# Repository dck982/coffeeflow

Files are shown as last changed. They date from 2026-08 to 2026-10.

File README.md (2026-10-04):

# coffeeflow

Modification d'une **Profitec Go** pour du *flow profiling* et du *brew by weight* : l'infusion se lance depuis un écran tactile, la pression se module, et elle s'arrête toute seule au poids cible.

## Machine d'origine

- Vanne solénoïde trois voies + pompe vibratoire 35 W + boiler
- Petit boîtier PID : consigne / mesure de température du boiler, chrono
- Vanne OPV pour limiter la pression
- Plomberie en **1/8"**
- Connexions électriques internes : cosses à languette **FASTON 6,3 × 0,8 mm** (pas de piggyback : la dérivation se fait dans un boîtier imprimé)
- Deux compartiments : **technique** (hydraulique, boiler, groupe, électricité) et **réservoir d'eau**
- Bouton **brew** en façade (Ø 16 mm) : démarrait vanne + pompe. **Supprimé** — le trou sert de passe-câble CAN vers l'écran
- LED de façade : ses cosses FASTON ont été réutilisées, la LED est réalimentée depuis le boîtier PS

## Ce que la modification ajoute

La modification pilote la pompe, la vanne et la résistance de chaudière :

1. **Pompe** — un dimmer AC 4 A en mode **DimmerLink** (I2C) fait varier la pression.
2. **Vanne solénoïde** — un SSR ouvre et ferme le circuit d'infusion.
3. **Chaudière** — le SSR Keysolu/Maxwell fourni avec la machine commande la résistance de chauffe ; sa commande 5 V passe par un HW-399 dans `boitier_pid`.

Plus de bouton brew, plus de relais NC de « mode manuel » : la commande passe par l'écran. Le système est alimenté dès que l'**interrupteur principal** de la machine est enfoncé.

Deux retours capteurs, sur le module interne :

- **Pression** sur la plomberie, en amont de la vanne (I2C 3,3 V)
- **Débit** en amont de la pompe, côté basse pression (le capteur ne tient que 3 bar)

La **température de la chaudière** vient de la sonde NTC vissée en G1/8 dans la chaudière. Son câble rejoint le boîtier de l'écran, proche de la sonde, où un ADS1115 la mesure via un pont alimenté par le **3V3 et le GND du port Sensor AD du Waveshare**. Voir [la calibration NTC/ADS1115](docs/ntc_ads1115_calibration.md).

Le **poids** vient d'une balance **Acaia Lunar** en **BLE**, lue par l'écran. La pesée du drip tray par cellule de charge est **abandonnée pour l'instant** (peser quelques grammes sur un plateau d'un kilo) — pièces et cotes conservées dans `print/parts/*_pesage*` et `docs/driptray.md`.

## Architecture électronique

**Cinq boîtiers imprimés, deux nœuds ESP32-S3.** Le 230 V ne sort pas de la machine.

```
             interrupteur principal (230 V L/N)
                          │
                    [boitier_ps]      intérieur, face ouest, le long du réservoir
                  alim RECOM 5 W · Wago            │
                          │                        └── L/N → LED de façade
              ┌───────────┴───────────┐
          5 V / GND                 L/N ×2
              │                       │
   ┌──────────┴──────────┐      [boitier_ac]   accolé à boitier_dc
   │                     │       dimmer · SSR
[boitier_dc]        [screen_*]        │    │
 XIAO ESP32-S3       Waveshare 4,3"   │    └── L/N → vanne solénoïde
 + Grove Shield      ESP32-S3         └────── L/N → pompe vibratoire
 + CAN Pal           UI · Wi-Fi · BLE
      │                   └── I2C ← ADS1115 ← NTC chaudière
      │                   │
      └──── bus CAN ──────┘   paire torsadée, par le trou Ø16 de l'ex-bouton brew
      │
      ├── I2C 3,3 V ─→ dimmer (DimmerLink)
      ├── GPIO ──────→ SSR vanne (M5Stack Unit SSR)
      ├── GPIO 3 ────→ [boitier_pid : HW-399] ─→ SSR chaudière ─→ résistance
      ├── I2C 3,3 V ←─ capteur de pression XDB401
      └── GPIO ──────← débitmètre Digmesa
```

| Nœud | Alias | Où | Rôle |
| --- | --- | --- | --- |
| **Waveshare 4,3" LCD Touch** (ESP32-S3-WROOM) | *screen*, *écran*, *waveshare* | façade, dans `screen_base` + `screen_wedge` | Interface utilisateur, algorithme d'infusion, **Wi-Fi et BLE** (Acaia Lunar) ; raccordement de la NTC chaudière via ADS1115 |
| **Seeed XIAO ESP32-S3** sur Grove Shield | *xiao*, *module interne*, *module capteurs*, *contrôleur* | intérieur, `boitier_dc`, zone froide entre le module PID et le cadran manomètre | Capteurs (XDB401, Digmesa) et actionneurs (dimmer pompe, SSR vanne, commande du SSR chaudière via HW-399) |

Les deux nœuds parlent **CAN**. L'écran est le seul à utiliser la radio.

Maquette Three.js de la machine (ouvrir dans le navigateur) : `docs/profitec_go.html`.

### Pourquoi un XIAO à l'intérieur

L'Atom Echo S3R de l'ancienne architecture est spécifié à **40 °C**. Le XIAO ESP32-S3 tient **85 °C**. Le compartiment technique monte à 45–50 °C : la marge de l'Atom est nulle, celle du XIAO est utilisable. L'écran Waveshare reste en façade, hors de cette enceinte.

---

## Boîtiers

| Boîtier | Pièces `print/parts/` | Où | Contenu |
| --- | --- | --- | --- |
| **PS** | `boitier_ps`, `couvercle_ps` | intérieur, contre la face **gauche** vue de face, le long de la séparation avec le réservoir | Alim RECOM, Wago 230 V (entrée + LED façade), Wago 5 V / GND |
| **DC** | `boitier_dc` | intérieur, **zone froide** entre le module PID et le cadran manomètre | XIAO + Grove Shield, Adafruit CAN Pal, Wago 5 V |
| **AC** | `boitier_ac` | accolé au DC | Dimmer 4 A DimmerLink, M5Stack Unit SSR |
| **PID** | `boitier_pid`, `couvercle_pid` | compartiment technique, près du contrôleur PID d'origine | HW-399, connecteurs XH et Wago de distribution 5 V / GND ; commande du SSR chaudière |
| **UI** | `screen_base`, `screen_wedge` | façade de la machine | Écran Waveshare 4,3", ADS1115 et raccordement NTC ; emplacement AMS1117 inutilisé |

Les boîtiers **AC et DC sont côte à côte et reliés par leur couvercle**, qui est commun aux deux (`couvercle_acdc`, assemblage `ensemble_boitiers`).

---

## Composants

| Rôle | Matériel retenu | Fiche |
| --- | --- | --- |
| UI / algo / radio | **Waveshare ESP32-S3-Touch-LCD-4.3** — 800 × 480, TJA1051T/3 CAN intégré, alim USB-C 5 V | `docs/datasheets/waveshare-4-3-lcd-touch.md` |
| MCU interne | **Seeed Studio XIAO ESP32-S3** sur **Grove Shield for XIAO** (8 ports Grove) | `docs/datasheets/xiao.pdf`, `docs/datasheets/grove-expansion-board.md` |
| Transceiver CAN côté XIAO | **Adafruit CAN Pal** (TJA1051T/3), [produit 5708](https://www.adafruit.com/product/5708) | — |
| Dimmer pompe | **RBDimmer AC Dimmer 4 A 1 canal**, logique 3,3 V, mode **[DimmerLink](https://www.rbdimmer.com/docs/dimmerlink-overview)** ([boutique](https://www.rbdimmer.com/shop/ac-dimmers-1/ac-dimmer-module-4a-1-channel-33v5v-logic-ac-400v-4a-6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)) | — |
| SSR vanne | **M5Stack Unit SSR** (2 A), commande 3,3–5 V, zero-crossing MOC3043M | `docs/datasheets/m5stack-unit-ssr.md` |
| SSR chaudière | **Keysolu/Maxwell KS53 D-24Z20N-LQ**, fourni avec la machine ; en série entre la phase de l'interrupteur principal et la résistance, suivie de la protection thermique puis du neutre ; commande DC +/− via HW-399, FASTON mâles 4,8 mm | [Câblage](docs/cablage.md#ssr-de-chaudière-fourni-avec-la-machine) |
| Interface SSR chaudière | **HW-399 4-channel Optocoupler**, voie IN4 / OUT4, logé dans `boitier_pid` | `docs/cablage.md` |
| Température chaudière | Sonde **NTC G1/8**, pont sur le port Sensor AD et breakout **ADS1115 16 bits** sur l'I2C de l'écran | [Calibration NTC/ADS1115](docs/ntc_ads1115_calibration.md) |
| Pression | **Yufavor XDB401**, I2C, filetage **G1/8** | `docs/datasheets/xidibei_xdb401.pdf` |
| Débit | **Digmesa FHKSC 932-9525-B**, buse **1,00 mm** | `docs/datasheets/flowmeter-digmesa.pdf`, `docs/debitmetres.md` |
| Alimentation | **RECOM RAC05-05SK/277/W** — 5 W, 5 V / 1 A, encapsulée, 85–305 VAC, version fils | `docs/datasheets/RAC05-K_277.pdf` |
| Poids | **Acaia Lunar**, BLE, lue par l'écran | — |
| Câble | **Helutherm 145** — 0,75 mm² pour les ajouts 230 V, 0,25 mm² en 5 V / signaux / CAN ; puissance chaudière en 1 mm² | `docs/datasheets/helutherm145.pdf` |

Actionneurs d'origine pilotés : vanne solénoïde **OLAB 08252L50-A14-1A-G** (bobine 08000BH-J5IV, 15 VA, 220/230 V 50/60 Hz, orifice Ø 1,4 mm, joint FKM, laiton CW510L, NSF) et pompe vibratoire **OLAB Silent Green 35 W**.

---

## Le module interne (XIAO)

### Ports Grove du Shield

Le Shield expose **deux colonnes de quatre connecteurs**. XIAO en bas : colonne de **gauche = L**, colonne de **droite = R** ; le port le plus proche du XIAO est **1**, le plus éloigné **4**.

| Port | Périphérique | Bus / GPIO | Alim | Câble |
| --- | --- | --- | --- | --- |
| **R1** | Capteur de pression XDB401 | I2C — SDA **GPIO 5**, SCL **GPIO 6** | 3,3 V | Grove à clip (quelques cm) → JST SM 4 pôles, débrochable **hors du boîtier** |
| **R2** | Débitmètre Digmesa | impulsions — **GPIO 44** (D7 sur le PCB) | 5 V (voir ci-dessous) | Grove 2 fils (noir + jaune) → JST SM 3 pôles → VH3.96 côté Digmesa |
| **R3** | Adafruit CAN Pal | TWAI — TX **GPIO 7** (fil blanc), RX **GPIO 8** (fil jaune) | 3,3 V | Grove → fils dénudés dans le bornier à vis du CAN Pal |
| **R4** | M5Stack Unit SSR, **vanne** | commande — **GPIO 9** (D10, fil jaune) | 5 V, repris hors du câble | Grove 10 cm, VCC coupé à ras côté XIAO |
| **L2** | HW-399 → SSR **chaudière** | commande — **GPIO 3** (D2 sur le PCB), LOW = chauffe active | 5 V côté sortie du HW-399 | Grove → XH 2 pôles (GND, IN4) ; XH 3 pôles (GND, VCC, OUT4) côté sortie |
| **L4** | Dimmer DimmerLink | I2C — SDA **GPIO 5**, SCL **GPIO 6** | 3,3 V | Grove |

Les repères `Dn` imprimés sur le Shield ne correspondent pas toujours aux GPIO natifs du XIAO. Le [tableau de câblage](docs/cablage.md#ports-grove-du-xiao) donne les deux numérotations.

**L4 est câblé en copie de R1** pour exposer une deuxième prise I2C. Le dimmer et le capteur de pression sont donc **sur le même bus** : le dimmer n'a pas de pull-up, il profite des **4,7 kΩ du XDB401**. Conséquence : retirer le capteur de pression laisse SDA / SCL sans tirage et le dimmer ne répond plus (sauf câble très court, sur les pull-ups internes de l'ESP32). Ne pas empiler un second 4,7 kΩ côté MCU tant que le XDB401 est sur le bus.

### Pastilles du Shield

Le Shield porte une rangée de pastilles à **gauche du XIAO** (carte tenue XIAO en bas, ports vers le haut). Les trois premières sont **5 V**, **GND**, **3V3** ; la septième est **D7 / GPIO 44**.

- Un **bornier 2 poles** est soudé sur les pastilles 5 V et GND : il alimente le XIAO depuis le boîtier PS et sert de point de reprise.
- **Filtre RC du débitmètre** : résistance **1 kΩ** entre la pastille 3 (3V3) et la pastille D7 (GPIO 44), condensateur **10 nF** à cheval entre la pastille 2 (GND) et la pastille D7. Le Digmesa est un collecteur ouvert NPN : il tire la ligne à la masse mais ne la monte jamais, c'est le tirage vers 3,3 V qui fixe le niveau haut, alors même que le capteur est alimenté en 5 V. GPIO en `INPUT`, pull-up interne éteinte.

### Bus CAN

Le CAN Pal est monté au **nord de `boitier_dc`**.

- Un **bornier à vis 2,54 mm** est soudé sur ses **quatre pastilles de gauche** (VCC, GND, RX, TX de gauche à droite) et rejoint le port **R3** par un câble dénudé d'un côté, Grove de l'autre.
- Les **deux pastilles de droite** (CANH, CANL) portent un **connecteur PCB femelle JST XH 2,54 mm**.
- La ligne est une **paire torsadée Helutherm 145 0,25 mm²** : **CANL = orange, CANH = gris**. Elle chemine dans la machine et sort par le trou de l'ancien bouton brew, équipé du passe-câble imprimé (`passe_cable` + `ecrou_passe_cable`).
- À l'autre bout, un **JST SM 2 poles** la relie à un câble **JST PH 2.0 2 poles** qui se branche sur le PCB du Waveshare (transceiver TJA1051T/3 intégré, CAN sur **GPIO15 TX / GPIO16 RX**, `CAN_SEL` = EXIO5 à l'état haut).
- Les **résistances de terminaison 120 Ω sont activées par jumper des deux côtés**.

---

## Alimentation

L'alim **RECOM RAC05-05SK/277/W** vit dans `boitier_ps` et alimente **tout** : les deux modules, les capteurs et les actionneurs basse tension.

### 230 V

- **Phase et neutre** viennent de deux **cosses FASTON isolées** prises sur l'**interrupteur principal** de la machine : tant qu'il n'est pas enfoncé (clic mécanique), rien n'est sous tension.
- Les deux fils (**Helutherm 145 0,75 mm²**) entrent dans `boitier_ps` par le **sud-ouest** et vont dans les deux Wago (**phase en bas, neutre en haut**).
- De ces mêmes Wago, phase et neutre **ressortent par le sud-ouest** pour alimenter la **LED de façade** — nécessaire, ses cosses FASTON ayant été réutilisées. **Phase brun, neutre bleu.**
- Phase et neutre ressortent aussi en **arc vers le nord** pour alimenter la RECOM, juste au nord dans le même boîtier. **Phase brun, neutre bleu.**
- Deux paires 0,75 mm² sortent vers `boitier_ac`, entrant par sa **face est**, chaque paire phase-neutre maintenue par de la gaine thermo (surface de boucle nulle) : **SSR (jaune/bleu)** et **dimmer (violet/bleu)**.
- Du **SSR** repartent phase et neutre vers la **vanne solénoïde** — **phase jaune, neutre bleu**.
- Du **dimmer** repartent phase et neutre vers la **pompe** — **phase violet, neutre bleu**.

### 5 V

- **VCC 5 V et GND** sortent de la RECOM vers les **Wago 3 poles au nord de `boitier_ps`**.
- De là, deux fils **0,25 mm² rouge / noir** vont à l'**écran**, via un **bornier adaptateur USB-C**.
- Deux autres fils rouge / noir vont à `boitier_dc`, dans les deux Wago du **compartiment sud-ouest** : **3 poles à gauche = 5 V**, **2 poles à droite = GND**.
- De ces bornes partent (a) le 5 V / GND du **XIAO**, par le bornier soudé aux pastilles du Shield, et (b) le 5 V vers la **Wago 3 poles du compartiment nord-ouest**.
- La Wago nord-ouest distribue le 5 V au **SSR** (fil du câble Grove dont le VCC a été coupé à ras côté XIAO, dénudé et repris ici) et au **Digmesa** (fil rouge du câble JST SM).
- Le `boitier_pid` reçoit aussi le **5 V / GND** pour les Wago et la sortie du HW-399 qui commande le SSR chaudière. Le pont NTC du boîtier de l'écran utilise le **3V3 / GND du port Sensor AD du Waveshare**.

### Le câble du Digmesa

Côté JST SM : **3 poles, 3 fils — rouge, noir, jaune**.

- **noir + jaune** sont sertis dans un connecteur **Grove** → port **R2**
- **rouge** part seul dans la **Wago du compartiment nord-ouest** → 5 V

Côté capteur, le câble est en **VH3.96** : rouge = VCC, noir = GND, jaune = signal.

---

## Capteurs

### Température chaudière — NTC G1/8

La sonde rejoint directement le boîtier de l'écran, voisin de la chaudière. Le **3V3 du port Sensor AD du Waveshare** rejoint la Wago NTC2, la NTC et l'entrée **A0** de l'ADS1115 ; le retour NTC rejoint la Wago NTC1, **A1** et une résistance mesurée de **2,193 kΩ** vers le **GND du même port Sensor AD**. L'ADS1115 16 bits est sur le port I2C du Waveshare. A0 permet de mesurer la tension réelle d'alimentation du pont. Le LDO AMS1117 du montage initial a été retiré après la correction de la référence de masse. Schéma et paramètres de conversion : [calibration NTC/ADS1115](docs/ntc_ads1115_calibration.md).

### Pression — Yufavor XDB401

Quatre fils : **rouge VCC**, **noir GND**, **vert SDA**, **blanc SCL**. Alimenté en **3,3 V** (l'emballage annonce 5 V ; l'émulation XDB401 est complète en 3,3 V, vérifié au banc). Pull-up **4,7 kΩ** sur SDA et SCL, non débrayables — ce sont elles qui tiennent tout le bus. Filetage **G1/8**, d'où le choix (plomberie machine en 1/8").

Gaine silicone avec une **fine feuille de blindage** : **pas de continuité feuille ↔ GND**. La relier à la masse **uniquement côté ESP32** ; côté sonde, coupée et isolée, pas de boucle.

Le connecteur **JST SM** est à l'extérieur du boîtier, à proximité immédiate : la sonde se débranche sans ouvrir.

### Débit — Digmesa FHKSC 932-9525-B (buse 1,00 mm)

| | 932-9525-B (retenu) | 932-9521-A (ancien) |
| --- | --- | --- |
| Buse | **1,00 mm** | 1,20 mm |
| Sens de montage | 0° | 0° |
| Impulsions | **2382 imp/L (0,42 g)** | 1925 imp/L (0,519 g) |
| Plage linéaire | **0,033 – 0,40 L/min** | 0,075 – 0,569 L/min |
| Pré-infusion 0,5 g/s | bas de plage | sous le linéaire |
| Perte de charge | ~0,48 bar vers 0,40 L/min | ~0,42 bar à 0,6 L/min |
| **Pression max** | **3 bar à 20 °C** | 3 bar à 20 °C |

Deux conséquences qui ne relèvent pas du câblage :

- **Le capteur va en amont de la pompe**, entre le réservoir et son entrée. La machine infuse à 9 bar et la pompe monte plus haut avant l'OPV : 3 bar de tenue interdisent le circuit haute pression.
- Le **1,00 mm** met une extraction de 36 g / 28 s (0,077 L/min) à 2,3 × son minimum, et 0,5 g/s au début du linéaire. Plafond 0,40 L/min : une chasse pompe ouverte peut saturer. Comparatif complet : `docs/debitmetres.md`.

---

## Câblage

| Domaine | Fil | Connectique |
| --- | --- | --- |
| 230 V — ajouts pompe/vanne/alimentation | **Helutherm 145 0,75 mm²**, paires L/N sous gaine thermo | Wago 221 à leviers ; FASTON 6,3 × 0,8 mm côté machine |
| 230 V — puissance chaudière | **1 mm²** | SSR chaudière fourni avec la machine, FASTON mâles 4,8 mm |
| 5 V / signaux / CAN | **Helutherm 145 0,25 mm²** | Grove, JST SM (débrochable), JST XH / PH 2.0, borniers à vis 2,54 mm, Wago 221 |

Détail fil par fil, couleurs et cheminement : `docs/cablage.md`. Passage intérieur → façade : le trou **Ø 16 mm** de l'ancien bouton brew, avec le passe-câble imprimé.

## Firmware

- **`boitier_dc` (XIAO ESP32-S3)** — I2C (DimmerLink, XDB401), GPIO du SSR vanne et du SSR chaudière, comptage d'impulsions du débitmètre, TWAI/CAN.
- **UI (Waveshare ESP32-S3)** — affichage et commandes, **algorithme d'infusion** (flow control, stop on weight), Wi-Fi, BLE vers l'Acaia Lunar. L'ADS1115 sur son I2C mesure la température chaudière par une NTC.

**État du firmware :** la commande diagnostique de chauffage dans `firmware/sensors` est implémentée et testée. La lecture NTC/ADS1115 dans `firmware/screen` est intégrée au code ; sa mesure reste à valider sur la machine. L'écran et `temperature.boiler.c` dans `/telemetry` utilisent la température chaudière ; le XDB401 reste disponible sous `temperature.xdb401`. Voir [le contrat firmware](docs/firmware.md) et [la calibration NTC](docs/ntc_ads1115_calibration.md).

Le mode DimmerLink retire tout besoin d'ISR zero-cross / PSM côté ESP32 : le Cortex du dimmer gère la détection de passage par zéro et le triac, le XIAO ne voit que de l'I2C. Sans **secteur** sur le dimmer, le module reste en `Calibrating...` et n'accepte pas les commandes.

Conception, protocole CAN et sécurité : `docs/firmware.md`. Build, flash et banc : `docs/firmware-build.md`. Style et structure de l'interface tactile (LVGL) : `docs/ui.md`, maquette à l'échelle `docs/ui-mockup.html`.

## Disposition mécanique

- **`boitier_ps`** — intérieur, contre la face gauche vue de face, le long de la séparation avec le réservoir.
- **`boitier_dc` + `boitier_ac`** — intérieur, zone froide entre le module PID et le cadran manomètre ; côte à côte, couvercle commun.
- **`boitier_pid`** — compartiment technique, près du contrôleur PID d'origine ; HW-399 et distribution 5 V / GND.
- **UI** — façade, à l'emplacement des boutons. Le wedge cadre l'écran (vissé par l'arrière), la base accueille le wedge (`screen_assembly`).

Pas de perçage du châssis : aimants Ø8 × 3 mm à l'intérieur, trou brew existant vers l'extérieur.

### Pièces imprimées (`print/`)

Projet [nurb](https://pypi.org/project/nurb/) : lancer `nurb` depuis `print/`. Export préféré : **3MF** dans `print/build/`. Sur cette machine, pour tout script Python (y compris hors `print/`) : **`uv run`**, pas le `python` système — détail dans `print/README.md`.

| Pièce | Où | Rôle |
| --- | --- | --- |
| `boitier_ps` / `couvercle_ps` | intérieur, face ouest | Alim RECOM, Wago 230 V et 5 V |
| `boitier_dc` | intérieur, zone froide | XIAO + Grove Shield, CAN Pal, Wago 5 V |
| `boitier_ac` | accolé au DC | Dimmer, SSR |
| `boitier_pid` / `couvercle_pid` | compartiment technique | HW-399, connecteurs XH et Wago de commande du SSR chaudière |
| `ensemble_boitier_pid` | — | Assemblage du boîtier PID et de son couvercle |
| `couvercle_acdc` | — | Couvercle unique des deux boîtiers |
| `ensemble_boitiers` | — | Assemblage DC + AC |
| `screen_wedge` / `screen_base` | façade | Cadre de l'écran Waveshare (vis M2.5 à l'arrière) et son berceau |
| `passe_cable` / `ecrou_passe_cable` | façade | Traversée du trou Ø 16 mm ex-bouton brew |
| `canal` | intérieur | Guidage des fils |
| `base_pesage` / `plateau_pesage` | drip tray | Pesée par cellule — **en pause** |

### Wago

Côté machine : FASTON 6,3 × 0,8 mm isolées nylon. Côté mod : Wago 221 (412, 415, 423 selon le compartiment). Pas de piggyback. Vis M3, inserts laiton M2.5 pour les cartes. Aimants 8 × 3 mm. Wago sans contact avec le fond ni les parois.

## Matière d'impression

**Les boîtiers sont imprimés en PLA HT recuit** — après recuit, la tenue en température monte à **140 °C**, très au-dessus des 40–50 °C du compartiment technique et sans le fluage du PLA standard à partir de ~45 °C. La machine tourne 10–15 min, deux fois par jour ; le reste du temps tout est à température ambiante et hors tension.

Le recuit fait retirer les pièces : les cotes fit-critiques (puits d'aimant, logements Wago, inserts) se vérifient **après** recuit, pas sur la pièce sortie du plateau.

*Atelier : Bambu Lab A1 Mini.*

## Dépôt

```
coffeeflow/
  README.md          ← cette vue d'ensemble
  docs/              ← câblage, débitmètres, drip tray, maquettes Three.js ; datasheets/
  print/             ← impressions 3D (nurb)
  tests/             ← scripts MicroPython de banc
  sound_test/        ← sketch Arduino de test Atom S3 (reliquat)
  tts/               ← génération WAV (Gemini TTS) pour le sketch
```

Contraintes et cotes d'une pièce : `print/parts/<nom>.md` + `print/measurements.toml`.

## Banc

Multimètre : **M5Stack Atom Echo S3R** + **Unit VMeter** (Grove PORT.A, ±36 V DC, bornes vis). Script `tests/test_vmeter.py`. Ne pas mesurer au GPIO de l'ESP32 (3,3 V max, pas 5 V).

## Sketch de test (`sound_test/`)

Reliquat Atom S3 Voice (Echo), ESP32-S3, USB-CDC natif, `M5.Speaker`, bouton `M5.BtnA`. FQBN : `m5stack:esp32:m5stack_atoms3`.

```
ls /dev/cu.usbmodem*
arduino-cli compile --fqbn m5stack:esp32:m5stack_atoms3 sound_test
arduino-cli upload -p /dev/cu.usbmodem2201 --fqbn m5stack:esp32:m5stack_atoms3 sound_test
```

Câble USB-C **data**. Si le port n'apparaît pas : autre câble, pas de hub, reset latéral. Le suffixe `usbmodem*` change à chaque reconnexion.

## TTS (`tts/`)

```
cd tts
uv run generate_tts.py "Espresso ready" -o startup.wav
```

Clé `GOOGLE_API_KEY` dans `tts/.env` (non commité). Pour embarquer le WAV :

```
xxd -i tts/startup.wav | sed 's/tts_startup_wav/startup_wav/; s/unsigned char/const uint8_t/; s/unsigned int/const unsigned int/' > sound_test/startup_wav.h
```

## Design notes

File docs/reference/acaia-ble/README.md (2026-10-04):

# Client BLE Acaia — code de référence

`blescale.h` / `blescale.cpp` : implémentation à la main, écrite dans un
projet antérieur (`coffeetracker.ino`, Arduino-ESP32), d'un client BLE GATT
pour une balance Acaia (Lunar). Déplacé ici depuis `tmp/ble-sample/` pour
servir de **référence de protocole** au moment d'écrire le client BLE de
`firmware/screen`.

**Ce code ne compile pas tel quel dans l'arbre `firmware/`.** Il est écrit
contre la pile Arduino-ESP32 (`BLEDevice.h`, `BLEAdvertisedDevice.h`,
`loop()` Arduino), alors que `firmware.md` a tranché pour ESP-IDF 5.x/6.x et
ses tâches FreeRTOS (le client BLE de l'écran utilisera donc l'API GATT
native d'ESP-IDF — `esp_gattc_api.h` / NimBLE — pas Arduino-ESP32, même si
Arduino-ESP32 reste une option de secours "composant IDF" citée dans
`firmware.md`). Sa valeur est dans **la logique du protocole Acaia**, pas
dans le code BLE bas niveau qui l'entoure : découverte du service, cadrage
des messages, décodage poids/temps/boutons, et l'émission périodique
(heartbeat + demande de notifications) sans laquelle la balance arrête
d'envoyer.

## Ce que fait ce code

- **Scan** — recherche un périphérique annonçant le service GATT de la
  balance (UUID passé au constructeur `BLEScale`), connexion, découverte du
  service/de la caractéristique, activation des notifications.
- **Cadrage des trames entrantes** (`provideData` accumule dans `msgBuf`,
  `loop()` le consomme) : préfixe `0xEF 0xDD`, puis `cmd` (1 octet),
  `payloadLen` (1 octet), `payload`, cas particulier `cmd == 0x20` = mise
  hors tension de la balance.
- **Notification `cmd == 12`** (`processNotification`) : le payload est
  lui-même une suite de sous-messages `[type][data...]`, démultiplexés par
  `processMessage` :
  - `type 5`, ≥6 octets : poids. `decodeWeight` — entier 32 bits
    little-endian sur 4 octets, `msg[4]` sélectionne le diviseur
    (10/100/1000/10000, donc le nombre de décimales), `msg[5] & 2` est le
    signe.
  - `type 7`, ≥3 octets : temps du chronomètre balance. `decodeTime` —
    `minutes*6000 + secondes*100 + dixièmes*10` (unité 10 ms), ramené à 0 si
    ≤ 20 (bruit de démarrage).
  - `type 8` : bouton pressé sur la balance (`TARE`/`START`/`STOP`/`RESET`),
    codes bruts 0/8/9/10.
- **Notification `cmd == 8`** (`processSettings`) : bit0 de `payload[0]` =
  état du chronomètre (marche/arrêt) ; `payload[2]` encode le mode de la
  balance (poids seul, poids+temps, débit, débit+tare auto, etc.) — pas
  décodé plus loin ici.
- **Émission périodique obligatoire** (`loop()`, toutes les 2,5 s) :
  `send_heartbeat` (un ID fixe puis un heartbeat vide) et
  `send_request_notifications`. **Sans ce battement, la balance arrête
  d'émettre** — ce n'est pas une notification GATT passive une fois
  souscrite, il faut la relancer.
- **Cadrage des trames sortantes** (`send_fixedlen_payload` /
  `send_payload`) : même préfixe `0xEF 0xDD`, `cmd`, payload, et un checksum
  sur 2 octets (somme des octets pairs / impairs du payload) — pas un CRC
  standard, juste deux accumulateurs 8 bits.

## Ce qui ne sert à rien à réutiliser tel quel

- Toute la mécanique `BLEAdvertisedDeviceCallbacks` / `BLEClientCallbacks` /
  `BLEScan` : à réécrire avec l'API GATT native ESP-IDF.
- Le `g_scanOwner` global (pointeur C brut vers l'unique instance vivante,
  nécessaire parce que le callback de fin de scan Arduino-ESP32 est un
  pointeur de fonction C sans contexte utilisateur) : problème spécifique à
  cette pile, ne se pose sans doute pas avec l'API ESP-IDF si elle permet de
  passer un contexte (`void *arg`) au callback GATT.
- `Serial.print` partout : à remplacer par `ESP_LOGx`, ou par un `LOG` du
  protocole CAN si l'info doit remonter jusqu'au Mac (voir la convention
  déjà en place dans `docs/firmware.md`).

## À vérifier avant de coder le client définitif

- **UUID exacts du service/caractéristique Acaia** : passés en paramètre du
  constructeur dans ce code, pas codés en dur ici — à retrouver (capture
  BLE d'une vraie Lunar, ou doc communautaire type `pyacaia`/`acaia_ble`)
  avant d'écrire le client ESP-IDF.
- **`msg[5] & 2` pour le signe du poids** : bit isolé, pas documenté au-delà
  de ce que ce code fait — à confirmer par test réel (poids négatif après
  tare, par exemple) plutôt que supposé correct par lecture du code seul.
- Le mode de balance (`payload[2]` dans `processSettings`) et le décodage
  des boutons ne sont pas exploités par l'algorithme d'infusion prévu
  (`firmware.md` : poids + un décalage d'anticipation) — à garder en tête
  mais pas nécessairement à porter en premier.

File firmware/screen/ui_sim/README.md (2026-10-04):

# Captures UI LVGL

Ce simulateur hôte compile le même `ui_home.cpp` et les mêmes polices que
l'image écran, avec un coeur factice et `LV_USE_SNAPSHOT=1`. Il n'emploie pas
SDL : `lv_snapshot_take()` rend directement un framebuffer 800 × 480.

```sh
cmake -S firmware/screen/ui_sim -B firmware/screen/ui_sim/build
cmake --build firmware/screen/ui_sim/build -j 4
mkdir -p firmware/screen/ui_sim/build/snapshots
firmware/screen/ui_sim/build/ui_snapshot firmware/screen/ui_sim/build/snapshots/home.ppm
sips -s format png firmware/screen/ui_sim/build/snapshots/home.ppm --out firmware/screen/ui_sim/build/snapshots/home.png
```

Le format PPM est volontaire : il évite d'ajouter un encodeur PNG à LVGL.
`sips` est disponible sur macOS pour consultation ou intégration dans un test
visuel. `build/snapshots/` est ignoré par Git avec les autres artefacts de
build. Les scénarios disponibles sont l'accueil (défaut), `no-scale`, `settings`,
`settings1`, `settings2`, `settings3`, `diagnostic`, `diagnostic-errors`,
`diagnostic-states`, `heating-menu-on`, `heating-menu-off`, `valve-menu`,
`valve-menu-open`, `valve-menu-heating`, `wifi-confirm`,
`dim`, `standby`, `cold` (lecture sonde à l'ambiante) et `cold-capped`
(sonde entre 50 et 60,5 °C). L'écran d'infusion se capture avec
`brew-<t>` (infusion synthétique à `t` secondes, par exemple `brew-3`, `brew-15`,
`brew-30`, `brew-41`, `brew-60`) ou `replay=<csv>@<t>` ; `brew` et `preinfusion`
sont des alias de `brew-30` et `brew-10`. Voir `docs/ecran-infusion.md`. Le simulateur ne
remplace pas un essai tactile ou RGB sur la dalle. Le scénario `wifi-mode`
capture le plein écran du mode Wi-Fi.

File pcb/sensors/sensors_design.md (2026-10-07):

# CoffeeFlow — contrôleur sensors sur XIAO ESP32-S3

Révision schématique B, 2026-10-07. `sensors.kicad_sch` est la feuille principale ;
`sensors_interfaces.kicad_sch` contient les interfaces. `sensors.pdf` et
`sensors.net.xml` reflètent ce schéma. Ouvrir le projet `sensors.kicad_pro`.

Le PCB a été mis à jour par l’utilisateur après la simplification du schéma.
J9/J10 ont ensuite été remplacés par une empreinte XIAO unique U1 ; les autres
éléments du PCB ont été conservés exactement. Le placement et le routage restent
à terminer. Les BOM, le sourcing, les positions et les archives de fabrication
existants décrivent encore la version MINI et ne représentent pas la nouvelle
version XIAO. Les scripts
`generate_bom.py` et `generate_manufacturing.py` vérifieront la concordance avec
le PCB ; attendre sa mise à jour avant de régénérer les fichiers de commande.
`generate_schematic.py` est un ancien générateur : ne pas le lancer sur ce schéma,
car il rétablirait la version MINI/USB/LDO.

## XIAO et alimentation

Le XIAO ESP32-S3 du stock est désormais représenté par **U1**, symbole
`Seeed_Studio_XIAO_Series:XIAO-ESP32-S3-SMD`, avec l’empreinte
**`Seeed_XIAO:XIAO-ESP32-S3-DIP`**. Ces deux bibliothèques sont celles installées
localement dans `~/Projects/OPL_Kicad_Library` ; les tables du projet les référencent.

Le symbole Seeed présente les broches 1–14 des headers et les pastilles 15–25
accessibles sous le module. L’empreinte DIP ne possède que les numéros 1–14 :
les pastilles 15–25 sont donc marquées NC dans le schéma. Le symbole conserve
son identité de bibliothèque ; seule son empreinte est remplacée par la variante DIP.

Sur le PCB, U1 remplace les deux sockets J9/J10, près de leur position précédente,
avec une rotation de 90° donnant l’USB-C vers le haut. Les broches 1–7 sont à
gauche du haut vers le bas ; 14–8 sont à droite du haut vers le bas. L’empreinte
Seeed possède quatorze trous et des pastilles SMD supplémentaires portant les mêmes
numéros. Deux barrettes femelles 1×7 au pas de 2,54 mm s’y montent ; l’écartement
entre rangées est de 15,24 mm. Le XIAO s’enfiche manuellement depuis le stock.

Sources locales : `../../docs/datasheets/xiao.pdf`, le schéma de la carte Seeed
`Seeed Studio XIAO ESP32S3/ESP32S3.kicad_sch`, la bibliothèque de symboles
`Seeed Studio XIAO Series Library/Seeed_Studio_XIAO_Series.kicad_sym`,
et l’empreinte installée `Seeed_XIAO.pretty/XIAO-ESP32-S3-DIP.kicad_mod`.

J1 conserve l'entrée 5 V régulée : broche 1 GND, broche 2 +5V.
Ce rail alimente le XIAO, le TJA1051 et les interfaces 5 V. La sortie 3V3 du
XIAO alimente VIO du TJA1051, le bus I2C, le TMP102 et le pull-up FLOW.
Le PWR_FLAG 3V3 représente la sortie du régulateur embarqué du XIAO.
Vérifier le budget 3,3 V avec les périphériques effectivement branchés.

L’ancien MINI U1, le LDO U2, USB-C J2, protection USB D1, BOOT/RESET, résistances USB/strapping/EN et
condensateurs associés C1–C6 ont été supprimés. USB, régulation et boutons
sont fournis par le XIAO. Débrancher l'alimentation externe J1 avant le flash
via l'USB-C du XIAO.

## Brochage

Le CAN, l'I2C, FLOW et VALVE reprennent les GPIO natifs du XIAO utilisés dans
`../../firmware/sensors/main/main.cpp` et `../../docs/cablage.md`.

| Fonction | GPIO natif | Nom Seeed | U1 / broche |
|---|---:|---|---|
| BOILER / HEATER_CMD | 4 | D3 | U1 / 4 |
| LED STATUS | 2 | D1 | U1 / 2 |
| I2C SDA | 5 | D4 | U1 / 5 |
| I2C SCL | 6 | D5 | U1 / 6 |
| VALVE_CMD | 9 | D10 | U1 / 11 |
| CAN RX | 8 | D9 | U1 / 10 |
| CAN TX | 7 | D8 | U1 / 9 |
| FLOW_PULSE | 44 | D7 | U1 / 8 |
| +5V | — | 5V | U1 / 14 |
| GND | — | GND | U1 / 13 |
| Sortie +3V3 | — | 3V3 | U1 / 12 |

U1 / 1 (D0/GPIO1), U1 / 3 (D2/GPIO3) et U1 / 7 (D6/GPIO43) sont NC.
GPIO2 et GPIO4 ne sont pas des broches de strapping ; GPIO3 reste inutilisé.
GPIO43, sortie UART0 au démarrage, reste inutilisé. FLOW conserve GPIO44,
entrée UART0 par défaut : le firmware actuel le reconfigure explicitement en GPIO.

## Note pour la mise en service — HEATER_CMD

**Modifier le firmware sensors seulement lors du passage au nouveau PCB.**
Le montage actuel reste sur `kGpioHeater = GPIO_NUM_3` (D2, HW-399).
La nouvelle carte utilise **HEATER_CMD sur GPIO4/D3, broche 4 de U1** :
il faudra définir `kGpioHeater = GPIO_NUM_4` et `kHeaterActiveLevel = 1`
(commande active HIGH pour Q3/Q2, au lieu de LOW pour le HW-399).
Précharger LOW avant de configurer la sortie et désactiver son pull-up.

HEATER_CMD et STATUS_LED ont été échangés pour faciliter le routage :
la LED externe utilise désormais **GPIO2/D1, broche 2 de U1**. GPIO2 et GPIO4
ne sont pas des broches de strapping. Le firmware n’est pas modifié dans
cette révision matérielle ; le changement sera nécessaire avant la mise en service.

## Circuits conservés et futur firmware

Toutes les connexions des composants conservés sont inchangées : TJA1051T/3
avec VCC 5 V, VIO 3,3 V et SLNT à GND, terminaison CAN 120 Ω, deux prises I2C
parallèles et pull-ups 4,7 kΩ, TMP102, FLOW avec pull-up 1 kΩ / filtre 10 nF,
VALVE avec pull-down, et sortie BOILER Q3/2N7002 + Q2/AO3401A.
D2 utilise désormais **C2297 / KT-0805G**, LED vert émeraude **0805**,
Basic chez JLCPCB (vérifié le 2026-10-07), avec l’empreinte
`LED_SMD:LED_0805_2012Metric`. Broche 1 = cathode/GND, broche 2 = anode.
Source : https://jlcpcb.com/partdetail/KT-0805G/C2297.
R25 reste à 1 kΩ : GPIO2 HIGH allume la LED. La fiche catalogue donne
Vf = 2,6–3,1 V à 5 mA ; sous 3,3 V avec 1 kΩ, le courant sera inférieur
à celui de la précédente LED jaune-verte. L’estimation avec cette plage
de Vf est 0,2–0,7 mA ; le courant réel dépend de Vf à faible courant.
Vérifier la luminosité au montage. Le PCB et ses fichiers de sourcing/BOM
conservent l’ancienne LED C2289/0603 jusqu’à la refonte du PCB.

**Le firmware n'a pas été modifié.** Il doit continuer à fonctionner sur le
montage actuel pendant la fabrication du futur PCB. Pour la nouvelle carte,
il faudra ultérieurement passer BOILER de GPIO3 à GPIO4 et surtout passer la
commande de **active LOW (HW-399 actuel) à active HIGH (montage MOSFET conservé)**.
Précharger LOW avant d'activer la sortie et désactiver le pull-up du chauffage.
R19/R21/R22 maintiennent la sortie BOILER coupée lorsque le GPIO est flottant.
Ajouter la commande LED sur GPIO2 si souhaitée. CAN/I2C/FLOW/VALVE ne demandent
pas de migration des GPIO par rapport au XIAO actuel.

## Vérification

ERC KiCad 10.0.6 : zéro violation. Comparaison des netlists avant/après :
toutes les appartenances aux nets des composants conservés sont identiques,
et chaque broche utilisée de U1 correspond au tableau ci-dessus, dans le schéma
et sur le PCB. Les 14 trous et l’écartement entre rangées ont été vérifiés.
PDF exporté sur deux pages ; première page vérifiée visuellement. Export SVG
du PCB réussi. Tous les éléments PCB autres que J9/J10/U1 sont inchangés ;
le routage existant n’a pas été retouché. Le firmware reste inchangé.

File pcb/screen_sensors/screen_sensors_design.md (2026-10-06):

# CoffeeFlow screen sensor board

The connected schematic is `screen_sensors.kicad_sch`; the manually
reworked layout is `screen_sensors.kicad_pcb`. The schematic PDF and
netlist are generated review copies. `screen_sensors_bom.csv` lists
component sourcing information; assembly exports still need final preparation.

## Connectors and supply

All connectors are through-hole, vertical/top-entry JST XH, for JLCPCB assembly.
Genuine XH pitch is 2.50 mm, often advertised as 2.54 mm by generic sellers.
Follow numbered pads rather than assuming left-to-right cable orientation.

| Connector | Pin 1 | Pin 2 | Pin 3 | Pin 4 |
|---|---|---|---|---|
| J1, Waveshare I2C | 3V3 | GND | SCL | SDA |
| J2, boiler NTC/PT1000 | 3V3 | boiler divider midpoint | — | — |
| J3, analog XDB401 | 3V3 | GND | pressure output | — |

J1 intentionally swaps SDA/SCL compared with the Waveshare connector order
(VCC, GND, SDA, SCL), to simplify PCB routing. Cross those two wires when
building the custom cable. The selected headers are B4B-XH-A, B2B-XH-A-R,
and B3B-XH-A for J1, J2 and J3 respectively; exact MPNs are in the BOM.

Waveshare H8 must select 3V3. There are no additional SDA/SCL pull-ups on this
board because Waveshare H7 supplies them. Check the total sensor current
against the Waveshare supply capacity once the pressure sensor arrives.

## Circuit and component references

- U1 ADS1115IDGSR: address 0x48, ADDR grounded, ALERT/RDY unused. A0 reads
  the local 3V3 that excites the boiler probe, A1 reads the boiler divider,
  A2 reads pressure, and A3 is unused with a schematic no-connect.
- R1 is 4.7 kΩ, 0.1%, from the boiler divider midpoint to GND. The NTC or
  PT1000 probe connects between 3V3 and that midpoint. The same fixed resistor
  supports either probe; use the corresponding firmware conversion/calibration.
- R3 is 1 kΩ, 1%, in series between the pressure sensor output and A2.
  With C3 = 10 µF it forms a low-pass filter with nominal cutoff about 16 Hz
  and time constant 10 ms. R3 is UNI-ROYAL 0603WAF1001T5E, JLCPCB C21190
  (basic). It provides modest current limiting, not complete input protection.
  The ADS1115 input (about 6 MΩ) loads R3 by about 0.02 %, absorbed by the
  pressure calibration.

  C3 was 100 nF (cutoff 1.59 kHz) until October 6, 2026. That only removes
  fast edges: 50 Hz and 100 Hz mains pickup passes, and the ADS1115 at 128 SPS
  averages over 7.8 ms, less than one mains period, so the pickup aliases into
  sample-to-sample noise. On the current wiring, the mounted sensor's A2 noise
  rose from 1.5 codes standard deviation in open air to 7.9 codes (0.006 bar)
  once its cable ran near the 230 V power switch wiring. Combined attenuation,
  RC filter times ADS1115 averaging:

  | R3 / C3 | Cutoff | Time constant | 50 Hz | 100 Hz |
  |---|---|---|---|---|
  | 1 kΩ / 100 nF (previous) | 1.59 kHz | 0.1 ms | 0.77 | 0.26 |
  | 1 kΩ / 10 µF (current) | 16 Hz | 10 ms | 0.23 | 0.04 |
  | 10 kΩ / 4.7 µF (rejected) | 3.4 Hz | 47 ms | 0.05 | 0.01 |

  The 47 ms option would add half a pressure-control period (10 Hz) of lag.
  X5R DC bias at the 0.4–2.4 V output lowers the effective capacitance a little,
  raising the cutoff slightly; this does not change the choice. The
  attribution of the noise to mains pickup is not yet confirmed: an RC test on
  the current wiring is planned.
- U2 SHT40-AD1B-R3: address 0x44, measures enclosure humidity and temperature.
  Leave its heater off during normal sampling. Keep the sensing opening free
  of flux, washing, coating and adhesives; specify no board wash for assembly.
  It uses the same top-side SMT reflow pass as U1.

| Capacitor | Value | Function |
|---|---|---|
| C1 | 100 nF | ADS1115 supply decoupling, close to VDD with a short ground return |
| C2 | 4.7 µF | Board bulk supply capacitance, near incoming power at J1 |
| C3 | 10 µF | Pressure ADC input to GND, paired with R3 (16 Hz low-pass) |
| C4 | 100 nF | Supply bypass at pressure connector J3 |
| C5 | 100 nF | SHT40 supply decoupling |

Capacitors were renumbered after layout: old C4 → C3, old C5 → C4, and
old C6 → C5. C1 and C2 retained their references. The original boiler filter
R2 and old C3 were removed at the user's request; the present C3 belongs to
pressure measurement. The boiler input has no added series resistor or filter
capacitor. The local NTC connector and its associated passives were removed
because U2 provides enclosure temperature.

## Power indicator

POWER is a red 0603 LED, Hubei KENTO KT-0603R (JLCPCB C2286, basic part).
R4 is 2.2 kΩ, 1%, UNI-ROYAL 0603WAF2201T5E (C4190, basic part).
The branch is `3V3 → R4 → POWER anode (pin 2) → cathode (pin 1) → GND`.
Nominal current is approximately 0.6 mA for a 2 V forward voltage. Brightness
and actual current depend on the LED forward voltage at this low current.
The LED indicates incoming power only, not working I2C communication.
Place the indicator near J1 and away from U2 when updating the PCB.
The LED and R4 are placed and routed on the PCB. The LED reference is
POWER in the PCB, schematic and source BOM.

Sources: [POWER](https://jlcpcb.com/partdetail/KT-0603R/C2286),
[R4](https://jlcpcb.com/partdetail/0603WAF2201T5E/C4190).

## PCB layout

The reworked board is 30 × 30 mm, with four 3.2 mm M3 mounting
holes. Components are on the top side; the underside is free of components.
J1 is at the north edge, J2 west, J3 south, and U2 near the east edge.

The bottom layer contains the GND plane and a few short signal/supply crossings.
A top-side GND pour uses the same outline and sensor-area exclusion as the
bottom plane. Both pours are connected; five redundant ground vias were removed,
leaving three ground vias (two near U1 and one for the SHT40 ground return),
plus six signal/supply vias. Each filled layer has one connected copper region.
Keep ordinary component ground returns short, using nearby vias where useful.
Keep vias outside solder pads to avoid requiring filled/capped via processing.
The SHT40 area is excluded from the ground pour to reduce board heat conduction;
its narrow ground connection terminates at a via outside that exclusion.
A via is electrically permitted for U2; avoiding a direct connection to a large
plane near the sensor is a thermal-design choice. Provide access to enclosure
air and keep the sensor away from display heat.

## Firmware and calibration

Read A0 and A1 with the same PGA, initially ±4.096 V:
`Rprobe = Rfixed * (A0_raw / A1_raw - 1)`.
Calibrate the assembled board. The bench value 4676 Ω inferred on September 29
belongs to the old measurement setup and must not automatically be reused.
Select the NTC curve or IEC 60751 Callendar–Van Dusen conversion for PT1000 as
appropriate. Detect open/short/out-of-range boiler readings and inhibit heating
appropriately. Do not interpret the unused A3 reading as a measurement.

The purchased XDB401 is invoiced as 3.3 V supply, 0.4–2.4 V output, 0–12 bar;
its body is engraved "SUP: 5V". Nominal conversion is
`pressure_bar = 6 * (Vout - 0.4)`. No voltage divider or amplifier is included.

Measured on the received sensor (October 6, 2026), on the current wiring
through the Waveshare-side ADS1115:

- The output is not ratiometric: 397.7 mV in open air with either a 5 V or a
  3.3 V supply. Use the absolute A2 voltage; A0 does not enter the pressure
  conversion.
- Open-air zero: 3167.3 codes (395.9 mV), 1.5 codes standard deviation. The
  sensor reads gauge pressure.
- Loading the 3V3 rail: none visible on A0.

Pending: whether to supply the sensor from 3.3 V or 5 V. At 3.3 V, the open
point is output headroom near full scale (about 2.04 V at the 9.8 bar OPV
plateau); it is checked by the pressure comparison against the previous I2C
sensor. This board only provides 3V3 on J3 pin 1, so a 5 V supply would need a
5 V source on J3. With the ADS1115 at 3.3 V, A2 must stay below about 3.6 V; if
a 5 V-supplied sensor failed high, R3 would limit the input current to about
1.4 mA.

## Assembly and maintenance

The BOM prefers basic parts where possible, with R1 retained at 0.1% precision; R3 and R4 use basic 1% parts.
Confirm current JLCPCB stock, exact MPN/footprint correspondence and through-hole
assembly availability before ordering. Final assembly BOM, placement file and
manufacturing outputs must be generated from the reviewed design.

The KiCad schematic and manually reworked PCB are the design sources of truth.
The initial Python generation/routing helpers and intermediate review backup
were removed after the manual rework. Matching schematic labels are electrically
connected.

KiCad may create `.history/` for automatic local snapshots; it is excluded from
Git. These snapshots can be managed through KiCad's File > Local History menu.

References:
- `../../docs/ntc_ads1115_calibration.md`, `../../docs/cablage.md`.
- [ADS1115 datasheet](https://www.ti.com/lit/ds/symlink/ads1115.pdf).
- [SHT4x datasheet](https://sensirion.com/resource/datasheet/sht4x).

## Manufacturing exports

Run `uv run ../generate_manufacturing.py .` (or `python3 ../generate_manufacturing.py .`)
from this directory after saving changes. Python requires no extra dependencies;
KiCad 10's `kicad-cli` must be installed. The script discovers the macOS app or
the executable on PATH; `--kicad-cli` overrides its location. Project-specific
connector centres and rotation corrections
are defined in `customize-manufacturing.py`, loaded automatically by the shared
exporter in `pcb/`.

Generated files are in ignored `manufacturing/`: Gerbers, separate plated and
non-plated drill files, JLCPCB BOM and placement CSVs, DRC report, source hashes,
fabrication-only ZIP and a combined `screen_sensors_jlcpcb.zip`. The source BOM
is `screen_sensors_bom.csv`; its values, footprints and LCSC numbers must
match the saved PCB. Physical DRC findings and schematic parity
differences stop the export.

Connector placement uses the transformed midpoint of each JST XH pin row,
so moving or rotating a connector does not require updating hardcoded positions.
U1 has a +270° JLCPCB model rotation correction. Review connector alignment and
chip/LED polarity in JLCPCB's assembly preview after each new upload.

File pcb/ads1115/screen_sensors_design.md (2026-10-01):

# CoffeeFlow screen sensor board

The connected schematic is `screen_sensors_draft.kicad_sch`; the manually
reworked layout is `screen_sensors_draft.kicad_pcb`. The schematic PDF and
netlist are generated review copies. `screen_sensors_draft_bom.csv` lists
component sourcing information; assembly exports still need final preparation.

## Connectors and supply

All connectors are through-hole, vertical/top-entry JST XH, for JLCPCB assembly.
Genuine XH pitch is 2.50 mm, often advertised as 2.54 mm by generic sellers.
Follow numbered pads rather than assuming left-to-right cable orientation.

| Connector | Pin 1 | Pin 2 | Pin 3 | Pin 4 |
|---|---|---|---|---|
| J1, Waveshare I2C | 3V3 | GND | SCL | SDA |
| J2, boiler NTC/PT1000 | 3V3 | boiler divider midpoint | — | — |
| J3, analog XDB401 | 3V3 | GND | pressure output | — |

J1 intentionally swaps SDA/SCL compared with the Waveshare connector order
(VCC, GND, SDA, SCL), to simplify PCB routing. Cross those two wires when
building the custom cable. The selected headers are B4B-XH-A, B2B-XH-A-R,
and B3B-XH-A for J1, J2 and J3 respectively; exact MPNs are in the BOM.

Waveshare H8 must select 3V3. There are no additional SDA/SCL pull-ups on this
board because Waveshare H7 supplies them. Check the total sensor current
against the Waveshare supply capacity once the pressure sensor arrives.

## Circuit and component references

- U1 ADS1115IDGSR: address 0x48, ADDR grounded, ALERT/RDY unused. A0 reads
  the local 3V3 that excites the boiler probe, A1 reads the boiler divider,
  A2 reads pressure, and A3 is unused with a schematic no-connect.
- R1 is 4.7 kΩ, 0.1%, from the boiler divider midpoint to GND. The NTC or
  PT1000 probe connects between 3V3 and that midpoint. The same fixed resistor
  supports either probe; use the corresponding firmware conversion/calibration.
- R3 is 1 kΩ, 1%, in series between the pressure sensor output and A2.
  Together with C3 it forms a provisional input low-pass filter, with nominal
  cutoff about 1.59 kHz and time constant 100 µs for low sensor source impedance.
  It provides modest current limiting, not complete input protection. R3 is UNI-ROYAL 0603WAF1001T5E, JLCPCB C21190 (basic). Confirm
  sensor output loading and assembled measurement accuracy when testing.
- U2 SHT40-AD1B-R3: address 0x44, measures enclosure humidity and temperature.
  Leave its heater off during normal sampling. Keep the sensing opening free
  of flux, washing, coating and adhesives; specify no board wash for assembly.
  It uses the same top-side SMT reflow pass as U1.

| Capacitor | Value | Function |
|---|---|---|
| C1 | 100 nF | ADS1115 supply decoupling, close to VDD with a short ground return |
| C2 | 4.7 µF | Board bulk supply capacitance, near incoming power at J1 |
| C3 | 100 nF | Pressure ADC input to GND, paired with R3 |
| C4 | 100 nF | Supply bypass at pressure connector J3 |
| C5 | 100 nF | SHT40 supply decoupling |

Capacitors were renumbered after layout: old C4 → C3, old C5 → C4, and
old C6 → C5. C1 and C2 retained their references. The original boiler filter
R2 and old C3 were removed at the user's request; the present C3 belongs to
pressure measurement. The boiler input has no added series resistor or filter
capacitor. The local NTC connector and its associated passives were removed
because U2 provides enclosure temperature.

## Power indicator

D1 is a red 0603 LED, Hubei KENTO KT-0603R (JLCPCB C2286, basic part).
R4 is 2.2 kΩ, 1%, UNI-ROYAL 0603WAF2201T5E (C4190, basic part).
The branch is `3V3 → R4 → D1 anode (pin 2) → cathode (pin 1) → GND`.
Nominal current is approximately 0.6 mA for a 2 V forward voltage. Brightness
and actual current depend on the LED forward voltage at this low current.
The LED indicates incoming power only, not working I2C communication.
Place the indicator near J1 and away from U2 when updating the PCB.
The LED and R4 are placed and routed on the PCB. The PCB LED reference is
POWER; the schematic and source BOM retain D1. The manufacturing exporter
explicitly maps D1 to POWER for the assembly files.

Sources: [D1](https://jlcpcb.com/partdetail/KT-0603R/C2286),
[R4](https://jlcpcb.com/partdetail/0603WAF2201T5E/C4190).

## PCB layout

The reworked board is 30 × 30 mm, with four 3.2 mm M3 mounting
holes. Components are on the top side; the underside is free of components.
J1 is at the north edge, J2 west, J3 south, and U2 near the east edge.

The bottom layer contains the GND plane and a few short signal/supply crossings.
Keep ordinary component ground returns short, using nearby vias where useful.
Keep vias outside solder pads to avoid requiring filled/capped via processing.
The SHT40 area is excluded from the ground pour to reduce board heat conduction;
its narrow ground connection terminates at a via outside that exclusion.
A via is electrically permitted for U2; avoiding a direct connection to a large
plane near the sensor is a thermal-design choice. Provide access to enclosure
air and keep the sensor away from display heat.

## Firmware and calibration

Read A0 and A1 with the same PGA, initially ±4.096 V:
`Rprobe = Rfixed * (A0_raw / A1_raw - 1)`.
Calibrate the assembled board. The bench value 4676 Ω inferred on September 29
belongs to the old measurement setup and must not automatically be reused.
Select the NTC curve or IEC 60751 Callendar–Van Dusen conversion for PT1000 as
appropriate. Detect open/short/out-of-range boiler readings and inhibit heating
appropriately. Do not interpret the unused A3 reading as a measurement.

The purchased XDB401 is specified as 3.3 V supply, 0.4–2.4 V output, 0–12 bar.
Nominal conversion is `pressure_bar = 6 * (Vout - 0.4)`.
Linearity with pressure does not establish ratiometry with supply: use absolute
A2 voltage initially. Verify zero pressure, a known pressure, wire assignments,
supply current, output impedance, startup, and output versus supply when the
sensor arrives. No voltage divider or amplifier is included.

## Assembly and maintenance

The BOM prefers basic parts where possible, with R1 retained at 0.1% precision; R3 and R4 use basic 1% parts.
Confirm current JLCPCB stock, exact MPN/footprint correspondence and through-hole
assembly availability before ordering. Final assembly BOM, placement file and
manufacturing outputs must be generated from the reviewed design.

The KiCad schematic and manually reworked PCB are the design sources of truth.
The initial Python generation/routing helpers and intermediate review backup
were removed after the manual rework. Matching schematic labels are electrically
connected.

KiCad may create `.history/` for automatic local snapshots; it is excluded from
Git. These snapshots can be managed through KiCad's File > Local History menu.

References:
- `../../docs/ntc_ads1115_calibration.md`, `../../docs/cablage.md`.
- [ADS1115 datasheet](https://www.ti.com/lit/ds/symlink/ads1115.pdf).
- [SHT4x datasheet](https://sensirion.com/resource/datasheet/sht4x).

## Manufacturing exports

Run `python3 generate_manufacturing.py` (or `uv run generate_manufacturing.py`)
from this directory after saving changes. Python requires no extra dependencies;
KiCad 10's `kicad-cli` must be installed. The script discovers the macOS app or
the executable on PATH; `--kicad-cli` overrides its location.

Generated files are in ignored `manufacturing/`: Gerbers, separate plated and
non-plated drill files, JLCPCB BOM and placement CSVs, DRC report, source hashes,
fabrication-only ZIP and a combined `screen_sensors_jlcpcb.zip`. The source BOM
is `screen_sensors_draft_bom.csv`; its values, footprints and LCSC numbers must
match the saved PCB. Physical DRC findings and unexpected schematic parity
differences stop the export. The known D1/POWER reference mismatch is reported.

Connector placement uses the transformed midpoint of each JST XH pin row,
so moving or rotating a connector does not require updating hardcoded positions.
U1 has a +270° JLCPCB model rotation correction. Review connector alignment and
chip/LED polarity in JLCPCB's assembly preview after each new upload.

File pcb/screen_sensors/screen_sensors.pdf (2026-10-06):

1 | 2 | 3 | 4 | 5 | 6 | 7 | 8
1 | 2 | 3 | 4 | 5 | 6 | 7 | 8

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
Size: A3 | Rev: | F Date:
KiCad E.D.A. 10.0.6 | Id: 1/1

## Title:

### File: screen_sensors.kicad_sch

### Sheet: /

C1

100nF | R4
| 2.2k

C5

100nF

ADDR | 1
ALERT/RDY | 2 GND

3

AIN0 4
AIN1 5
AIN2 6
AIN3 7 | VDD

8

SDA 9

SCL 10

U1

ADS1115IDGSR C2

4.7uF | 1

2
3

J3

XDB401_ANALOG SDA 1

SCL 2 | VDD

## 3 VSS

4

U2

SHT40-AD1B | POWER RED / | 1k R3 | C3

10uF #FLG02 PWR_FLAG

C4

100nF 1
2
3
4

# J1 WAVESHARE_I2C 1

2

J2 BOILER_PROBE | 4.7k 0.1% R1 #FLG01 PWR_FLAG

SDA SCL GND
3V3 | GND

3V3 BOILER_ADC

3V3

SDA

GND

SCL | GND

3V3

3V3 | PRESS_ADC
SDA | 3V3 | PRESS_ADC | GND

GND

PRESS_SIGNAL SCL | GND

GND

3V3 | PRESS_SIGNAL GND

3V3

GND

3V3

3V3 PRESS_ADC

3V3

3V3

GND

BOILER_ADC

GND

GND

### BOILER_ADC 5 / Enclosure humidity + temperature - 0x44

Rprobe = R1 * (A0/A1 - 1). Use new-board calibration. Probe between 3V3 and DIV. Fixed resistor from DIV to GND. No added I2C pull-ups: Waveshare H7 already has 4.7k. POWER: 3V3 present; does not verify I2C communication. 3 / Boiler NTC or PT1000

No voltage divider / amplifier needed. Pressure = 6*(Vout-0.4) bar nominal. Verify supply current, output impedance, startup and ratiometry before manufacture. Humidity sensor opening must remain free of flux, coating and adhesives. Place near board edge, exposed to box air, away from display heat.

1 / Waveshare power and I2C | 2 / ADS1115 - 0x48

A0 = 3V3; A1 = boiler; A2 = pressure; A3 unused. 4 / XDB401 analog: 0.4-2.4 V / 0-12 bar

3.3 V ONLY. Waveshare H8 must select 3V3. All matching labels are electrically connected. CoffeeFlow - screen sensor board / electrical review draft

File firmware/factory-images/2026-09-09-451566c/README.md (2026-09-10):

# Images factory — 2026-09-09

Source : commit [`451566c980ccb6935284ebad8b9b5a400a2db413`](../../../../.git/)
(`firmware phase 6, lot 1 : restructuration de screen/, vérifiée sur matériel`).
Version PONG : `0.2.9`. ESP-IDF : `6.1.0`.

Ces images sont le filet de récupération immuable, pas l'application
fonctionnelle :

- `screen-factory.bin` : pont UART USB ↔ CAN, PING/PONG et réception OTA
  locale de l'écran. Les trames destinées aux capteurs sont relayées sur CAN,
  ce qui permet de reflasher les deux cartes avec le seul USB de l'écran.
- `sensors-factory.bin` : CAN, PING/PONG, OTA et repli sûr des sorties.

Elles s'écrivent **uniquement** à l'offset `0x20000`, dans la partition
`factory`, avec la table de partitions correspondante. Ne jamais utiliser
`idf.py flash` avec l'application fonctionnelle : elle va à une partition OTA
et ne tient de toute façon pas dans factory.

| Fichier | SHA-256 |
| --- | --- |
| `screen-factory.bin` | `fb05203840294191584dfc962c79c965a151beace5699eac8de12299111fa4dd` |
| `sensors-factory.bin` | `9e0bbd94e9730a5df153b5f5eb24f17427ef0d293a7aa1e7fb517445f52ab929` |

## Écriture initiale

Écrites le 2026-09-10, avec vérification par hash après écriture :

| Cible | Port USB | MAC | Offset |
| --- | --- | --- | --- |
| XIAO capteurs, flash 8 Mo | `/dev/cu.usbmodem1101` | `a4:cb:8f:d2:67:64` | `0x20000` |
| Waveshare écran, flash 16 Mo | `/dev/cu.usbmodem5B790235091` | `44:1b:f6:ca:6a:58` | `0x20000` |

L'écriture ne modifie ni `otadata`, ni NVS, ni les partitions OTA : elle ne
fait donc pas démarrer factory immédiatement. Pour éprouver un jour le chemin
de récupération, sélectionner factory explicitement, vérifier PING/PONG par
l'USB de l'écran, puis reflasher une image OTA fonctionnelle avant de remettre
la machine en service.

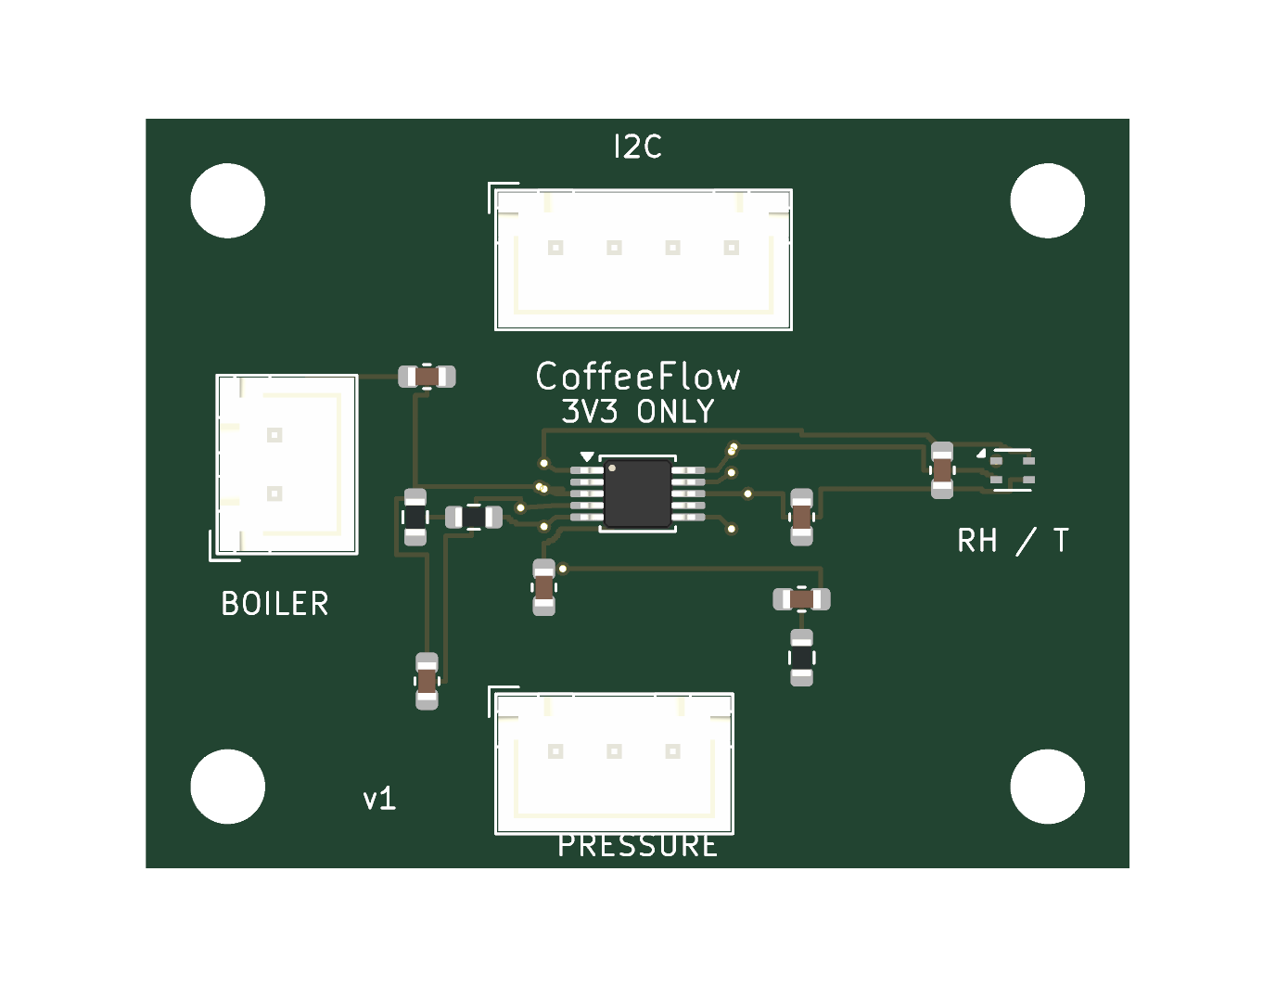
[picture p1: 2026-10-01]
pcb/screen_sensors/screen_sensors_top.png

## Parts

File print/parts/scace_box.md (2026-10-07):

# scace_box

<!-- AUTO: regenerated by `nurb card`. Do not hand-edit. -->
Size: 72.52 x 31.84 x 45.00 mm, 27283.4 mm3, 1 solid, 40 faces
Checks: clean
<!-- /AUTO -->

## What it is

## Design notes

## Don't

## Changelog

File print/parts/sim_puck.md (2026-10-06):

# sim_puck

<!-- AUTO: regenerated by `nurb card`. Do not hand-edit. -->
Size: 57.00 x 57.00 x 13.50 mm, 33743.7 mm3, 1 solid, 35 faces
Checks: 2 findings: 2 warn (min_wall, overhang)
<!-- /AUTO -->

## What it is

## Design notes

## Don't

## Changelog

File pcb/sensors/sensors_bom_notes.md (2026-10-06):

# Sensors JLCPCB BOM

Checked against the saved PCB and both schematic sheets on **2026-10-05**.

**46 fitted components: 29 Basic, 17 Extended.** The upload BOM contains all 46 components in 26 part groups. Basic/Extended classifications and stock were read directly from JLCPCB catalog data; the dated snapshot is in `sensors_sourcing.json`. Stock and classifications can change.

- `sensors_bom.csv`: full per-component source BOM, with PCB and schematic references, exact MPN, LCSC code, class, assembly method and notes.
- `sensors_jlcpcb_bom.csv`: grouped four-column JLCPCB upload BOM using the actual PCB references.
- `sensors_manual_bom.csv`: header-only; no parts are currently selected for manual assembly.
- `sensors_bom_validation.json`: component counts, reference mapping and source hashes.

Regenerate from the saved designs with `uv run sensors/generate_bom.py` from `pcb/`, or `uv run generate_bom.py` from `sensors/`. This reads the saved designs, validates component identity/footprints/DNP and writes only BOM artifacts. Edit `sensors_sourcing.json` when changing part selections.

## Part selections

| PCB references | Part | JLCPCB | Class | Assembly | Catalog stock* |
|---|---|---|---|---|---:|
| 5V, BOILER, CAN | B2B-XH-A(LF)(SN) | [C158012](https://jlcpcb.com/partdetail/x/C158012) | Extended | THT | 299,933 |
| BOOT, RESET | TS-1088-AR02016 | [C720477](https://jlcpcb.com/partdetail/x/C720477) | Basic | SMT | 777,290 |
| C1 | CL21B475KOFNNNE | [C107365](https://jlcpcb.com/partdetail/x/C107365) | Extended | SMT | 46,921 |
| C2, C5, C8, C9, C10 | CC0603KRX7R9BB104 | [C14663](https://jlcpcb.com/partdetail/x/C14663) | Basic | SMT | 57,209,141 |
| C3 | TAJB226K010RNJ | [C7198](https://jlcpcb.com/partdetail/x/C7198) | Extended | SMT | 39,323 |
| C4 | CL21B106KOQNNNE | [C95841](https://jlcpcb.com/partdetail/x/C95841) | Extended | SMT | 394,770 |
| C6 | CL10B105KA8NNNC | [C29936](https://jlcpcb.com/partdetail/x/C29936) | Extended | SMT | 268,058 |
| C12 | 0603B103K500NT | [C57112](https://jlcpcb.com/partdetail/x/C57112) | Basic | SMT | 6,657,115 |
| D1 | TPD2E2U06DCKR | [C1855726](https://jlcpcb.com/partdetail/x/C1855726) | Extended | SMT | 11 |
| FLOW, VALVE | B3B-XH-A(LF)(SN) | [C144394](https://jlcpcb.com/partdetail/x/C144394) | Extended | THT | 174,813 |
| I2C A, I2C B | HY-4A | [C722737](https://jlcpcb.com/partdetail/x/C722737) | Extended | THT | 1,106 |
| J2 | USB4105-GF-A-060 | [C3025063](https://jlcpcb.com/partdetail/x/C3025063) | Extended | SMT | 1,287 |
| Q2 | AO3401A | [C15127](https://jlcpcb.com/partdetail/x/C15127) | Basic | SMT | 815,848 |
| Q3 | 2N7002 | [C8545](https://jlcpcb.com/partdetail/x/C8545) | Basic | SMT | 1,601,156 |
| R2, R3, R11, R17, R21, R23, R24 | 0603WAF1002T5E | [C25804](https://jlcpcb.com/partdetail/x/C25804) | Basic | SMT | 29,606,163 |
| R4, R5 | 0603WAF5101T5E | [C23186](https://jlcpcb.com/partdetail/x/C23186) | Basic | SMT | 25,206,931 |
| R6, R7 | 0603WAF220JT5E | [C23345](https://jlcpcb.com/partdetail/x/C23345) | Basic | SMT | 8,966,004 |
| R12 | 1206W4F1200T5E | [C17909](https://jlcpcb.com/partdetail/x/C17909) | Basic | SMT | 529,895 |
| R13, R14 | 0603WAF4701T5E | [C23162](https://jlcpcb.com/partdetail/x/C23162) | Basic | SMT | 22,251,089 |
| R15, R22, R25 | 0603WAF1001T5E | [C21190](https://jlcpcb.com/partdetail/x/C21190) | Basic | SMT | 21,294,251 |
| R19 | 0603WAF1003T5E | [C25803](https://jlcpcb.com/partdetail/x/C25803) | Basic | SMT | 22,034,608 |
| D2 | KT-0603YG | [C2289](https://jlcpcb.com/partdetail/x/C2289) | Extended | SMT | 29,232 |
| U1 | ESP32-S3-MINI-1U-N8 | [C2980299](https://jlcpcb.com/partdetail/x/C2980299) | Extended | SMT | 1,402 |
| U2 | AMS1117-3.3 | [C6186](https://jlcpcb.com/partdetail/x/C6186) | Basic | SMT | 1,056,675 |
| U4 | TJA1051T/3/1J | [C38695](https://jlcpcb.com/partdetail/x/C38695) | Extended | SMT | 287,313 |
| U5 | TMP102AIDRLR | [C99269](https://jlcpcb.com/partdetail/x/C99269) | Extended | SMT | 41,187 |

*Catalog `overseasStockCount`, not a reservation or a guarantee of quantity available to your order. D1 had only 11 units and `canPresaleNumber=0`; resolve its availability before submitting an assembly order. Other assigned parts had much larger stock.

## Decisions and remaining assembly details

**Keep X7R by default.** C1/C4/C6 retain the dielectric specified in the original BOM. There are footprint-compatible Basic X5R alternatives below, but they reduce the dielectric temperature rating from 125°C to 85°C. They are documented options, not selected substitutions. All MLCCs lose capacitance under DC bias; their voltage rating alone does not guarantee effective capacitance.

| Reference | Selected X7R (Extended) | Optional X5R (Basic) |
|---|---|---|
| C1 | C107365, CL21B475KOFNNNE, 4.7µF 16V 0805 | [C1779](https://jlcpcb.com/partdetail/x/C1779), CL21A475KAQNNNE, 4.7µF 25V 0805 |
| C4 | C95841, CL21B106KOQNNNE, 10µF 16V 0805 | [C15850](https://jlcpcb.com/partdetail/x/C15850), CL21A106KAYNNNE, 10µF 25V 0805 |
| C6 | C29936, CL10B105KA8NNNC, 1µF 25V 0603 | [C15849](https://jlcpcb.com/partdetail/x/C15849), CL10A105KB8NNNC, 1µF 50V 0603 |

**C3 stays solid tantalum.** TAJB226K010RNJ, 22µF/10V, case B 3528-21, fits the Kemet-B land pattern. The local AMS1117 datasheet, page 4, recommends 22µF solid tantalum for stability. Pin 1 is positive; do not replace this part with an MLCC or polymer capacitor solely to reduce loading fees.

**BOOT/RESET use the current footprint.** C720477 TS-1088-AR02016 is Basic in the current JLCPCB catalog, and is the exact part named by KiCad’s `SW_SPST_TS-1088-xR020` footprint. The old TL3342F160QG entry is a different, larger switch.

**STATUS uses a low-forward-voltage yellow-green LED.** C2289 KT-0603YG is Extended, 0603, nominal Vf 2.0–2.2V. This matches the design’s approximately 1.1–1.3mA indication with R25=1k and 3.3V. Basic 0805 green LEDs do not fit; the checked 0603 emerald-green options were Extended and have less voltage headroom. Pin 1 is cathode/GND.

**CAN keeps NXP’s /3 variant.** C38695 is TJA1051T/3/1J, the current ordering code for the SO8 device with pin 5 VIO. The local TJA1051 datasheet confirms the /3 pinout. Do not substitute TJA1051T without /3 or an unverified clone.

**U1 keeps the exact ESP32-S3-MINI-1U-N8.** C2980299 is the Espressif module. JLCPCB’s package label says VFQFN-56-EP; the local Espressif datasheet specifies the actual 15.4×15.4mm module and its land pattern. Match by exact MPN and manufacturer drawing. Confirm JLCPCB assembly-service eligibility and polarity/rotation for the module during quote review.

**USB-C uses GCT USB4105-GF-A-060.** C3025063 is a listed variant of the assigned footprint; it has shorter 0.60mm shell stakes than the unsuffixed part. [GCT drawing](https://gct.co/files/drawings/usb4105.pdf) provides the shared PCB land pattern. Confirm shell engagement for the board thickness. D1 is the exact TI 3-pin SC-70 DCK part, with I/O on pins 1/2 and GND on 3 ([TI datasheet](https://www.ti.com/lit/ds/symlink/tpd2e2u06.pdf)); the 5-pin DRL version is incompatible.

**Both I2C/Grove connectors use CAX HY-4A / C722737.** The user selected this Extended THT part after confirming its model displays in JLCPCB. The project-local `Sensors_Local:CONN-TH_HY-4A` footprint is now assigned in schematic and PCB, with the supplier 3D model, a KiCad-compatible pad order and 1.0mm drills. It retains the 4-pin 2mm pin layout. Numbered supplier pads match the KiCad pad order with a -90° CPL rotation offset. Position uses the numbered pin-row midpoint. The linked supplier PDF contains unrelated PH-series information and is not used as mechanical evidence.

**Seven connectors need through-hole assembly.** 5V/CAN/BOILER share C158012, the white JST B2B-XH-A(LF)(SN). FLOW/VALVE share C144394, JST B3B-XH-A(LF)(SN). I2C A/B both use C722737. For full outsourced assembly select a service supporting these THT parts; otherwise fit them manually and remove those references from the assembly upload.

## Reference reconciliation and scope

The old BOM still included J5, used obsolete horizontal J1/J3 connectors, and listed the previous switch footprint. The new BOM follows the saved PCB. UUIDs associate each footprint with its schematic symbol, so connector names are not guessed by value.

| Schematic | PCB/upload |
|---|---|
| J1 | 5V |
| J8 | BOILER |
| SW1 | BOOT |
| J3 | CAN |
| J6 | FLOW |
| J4 | I2C B |
| J5 | I2C A |
| D2 | STATUS |
| SW2 | RESET |
| J7 | VALVE |

Both schematic sheets now contain hidden `LCSC` fields and updated `MPN` fields matching the sourced JSON: all 46 LCSC IDs are populated, including both J4/J5 CAX Grove connectors. Existing references and schematic connectivity are unchanged. Reload the schematics from disk in any open editor before using Update PCB from Schematic with “Update footprint fields from symbols”. Review the reference/value differences listed above when applying the update. PCB fields and geometry were not changed by this schematic update.

Manufacturing outputs are now in `manufacturing/`: `sensors_jlcpcb.zip` contains fabrication, BOM and placement files; `sensors_gerbers.zip` contains fabrication files only. Physical DRC passed with zero violations and zero unconnected items. The project-local `customize-manufacturing.py` accepts only the ten intentional reference-label pairs listed above and the four specific mechanical mounting holes. It verifies renamed footprints against their schematic UUIDs, values, footprints and sourcing fields, and independently compares schematic/PCB connected net membership on every export. Other parity findings still stop exports. Placement corrections in `customize-manufacturing.py` now use numbered pin-row midpoints for XH/Grove connectors. Relative rotation offsets: U1=0°, U2=180°, U4=270°, U5=180°, C3/Q2/Q3=180° and D1=-90° (user-confirmed), and C158012 connectors 5V/CAN/BOILER=180°. Supplier CAD numbered pads were compared against KiCad for all U parts and JST connectors; see `sensors_placement_validation.json`. This is evidence for the selected supplier CAD orientation, not independent confirmation of JLCPCB’s private assembly models. C722737 Grove supplier CAD was retrieved: its midpoint and -90° rotation correction match the four numbered pads. Check Grove alignment and all corrected placements in JLCPCB’s preview. These changes affect only manufacturing placement files; PCB geometry is unchanged.

`generate_schematic.py` is an older schematic seed and still contains earlier design choices; running it would overwrite edited schematics and the sourced BOM. Use `generate_bom.py` for this saved layout.

C722737 PCB synchronization is complete. Source/upload BOMs, placement CSV and manufacturing archives are regenerated from the saved board. Physical DRC passed with zero violations and zero unconnected items; the 24 known reference-label/mounting-hole parity findings were accepted only after component identity and independent connectivity checks. The current archive selects C722737 / HY-4A and the local CONN-TH_HY-4A footprint.

The saved board is now 33×70mm. J4 (PCB I2C B) and J5 (PCB I2C A) are two parallel sockets on the same SCL/SDA/3V3/GND bus, not independent buses. Duplicated footprint I2C A was assigned its own J5 symbol UUID; only this schematic-link metadata was changed in the PCB. All previous schematic net memberships were verified unchanged after adding J5. ERC and physical DRC are clean. Both Grove placements use pin-row midpoints and the existing -90° correction.

Assembly upload aliases: `I2C A` → `I2CA`, `I2C B` → `I2CB`. JLCPCB parses spaces differently between BOM and CPL, so both exports use the same space-free names. PCB and schematic references are unchanged. The source of this mapping is `AssemblyReferenceAliases` in `sensors_sourcing.json`; alias collisions or unsupported characters stop both exporters. Verified 46 matching unique upload references and unchanged placement coordinates/rotations.

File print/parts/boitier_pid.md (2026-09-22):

# boitier_pid

<!-- AUTO: regenerated by `nurb card`. Do not hand-edit. -->
Size: 60.00 x 50.00 x 28.60 mm, 17258.3 mm3, 1 solid, 114 faces
Checks: 1 finding: 1 warn (min_wall)
<!-- /AUTO -->

## What it is

Boîtier ouvert pour le contrôleur PID : le HW399 se clipse dans le compartiment ouest, tandis que les Wago 221-412 et trois 221-423 se rangent debout à l'est. Le côté sud reste ouvert pour le passage des câbles ; deux logements d'aimants et deux corbeaux à inserts M3 reçoivent le couvercle.

## Design notes

Enveloppe définie par les mesures : 60 × 50 × 28,6 mm, fond de 1,6 mm et murs de 1,68 mm. Les dimensions du HW399, des Wago, des aimants et de l'ouverture sous le cache externe viennent de `measurements.toml`; seules les dimensions d'usage (`hauteur`, `wago_surplomb`, `hauteur_hw399`) restent ajustables.

Le HW399 est porté par quatre plots et retenu par une paroi/surplomb imprimable. Les Wago sont guidés par des seuils de 1 mm et des surplombs à 45°, pas par des étagères horizontales. Les puits d'aimants conservent une peau de fond et les inserts M3 sont portés par des corbeaux depuis les parois, afin de ne pas créer de tours fragiles depuis le fond.

Les arêtes verticales hors bords nord et sud sont polies à 1 mm ; ces bords restent nets pour préserver les dégagements et l'interface du couvercle.

```toml
[part]
min_wall = 0.6
```

## Don't

- Ne pas remettre un mur au sud : c'est le passage des câbles.
- Ne pas remplacer les surplombs Wago ou le clip HW399 par des tablettes carrées : leurs dessous à 45° sont nécessaires à une impression sans support.
- Ne pas déplacer les dimensions d'encombrement dans les paramètres : elles partagent le référentiel de mesures avec le couvercle.
- Ne pas transformer les corbeaux d'insert M3 en piliers depuis le fond ; ils doivent rester ancrés aux parois.
- Ne pas polir les bords nord et sud conservés nets : ils sont exclus pour éviter les collisions de chanfreins et les changements de jeu.

## Changelog

- 2026-09-21 — Card renseignée : boîtier PID, logements HW399/Wago, aimants et inserts M3 documentés. Géométrie 60,00 × 50,00 × 28,60 mm, checks clean.

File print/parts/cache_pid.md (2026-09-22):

# cache_pid

<!-- AUTO: regenerated by `nurb card`. Do not hand-edit. -->
Size: 74.00 x 30.00 x 5.00 mm, 10419.2 mm3, 1 solid, 28 faces
Checks: clean
Variant plaque: 58.00 x 25.00 x 2.00 mm, 2756.0 mm3, 1 solid, 14 faces, 0 under 1.0mm2, clean
<!-- /AUTO -->

## What it is

## Design notes

```toml
[part]
min_wall = 0.6

[variants.plaque]
note = "Plaque intercalaire"

[variants.plaque.params]
plaque = 1

```

## Don't

## Changelog

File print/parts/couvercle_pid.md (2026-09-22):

# couvercle_pid

<!-- AUTO: regenerated by `nurb card`. Do not hand-edit. -->
Size: 60.00 x 50.00 x 4.60 mm, 5411.5 mm3, 1 solid, 26 faces
Checks: clean
<!-- /AUTO -->

## What it is

Couvercle plat du `boitier_pid`. Sa plaque recouvre le boîtier et son rebord intérieur guide l'emboîtement contre les faces internes des murs ; les découpes libèrent les deux corbeaux à inserts M3.

## Design notes

Plaque de 1,6 mm, 60 × 50 mm. Le cadre intérieur a 1,2 mm d'épaisseur (trois périmètres), descend de 3 mm dans la cavité et conserve 0,3 mm de jeu contre les murs de 1,68 mm du boîtier. Le côté sud du rebord est retiré afin de ne pas fermer l'ouverture de câbles.

Les évidements autour des corbeaux ménagent 0,5 mm de marge ; les deux perçages Ø3 mm correspondent aux vis des inserts M3. Le couvercle est miroir en X : après le retournement à 180° dans l'assemblage, chaque découpe revient devant son corbeau.

Les arêtes verticales hors bords nord et sud sont polies à 1 mm. Les bords de l'ouverture restent nets pour préserver le jeu avec le boîtier.

## Don't

- Ne pas fermer le cadre au sud : cela obstruerait le passage de câbles du boîtier.
- Ne pas réduire `gouttiere_jeu` sous 0,3 mm sans coupon d'ajustement : le rebord est une interface imprimée contre imprimée.
- Ne pas supprimer les évidements des corbeaux ni décaler leurs trous : leurs coordonnées viennent de `boitier_pid.corbels()`.
- Ne pas retirer le miroir X : l'assemblage retourne le couvercle pour engager son rebord dans le boîtier.
- Ne pas polir les bords nord et sud exclus ; ils déterminent les dégagements d'emboîtement.

## Changelog

- 2026-09-21 — Card renseignée : couvercle à rebord guidé, dégagements de corbeaux et perçages M3 documentés. Géométrie 60,00 × 50,00 × 4,60 mm, checks clean.

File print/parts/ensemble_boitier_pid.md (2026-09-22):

# ensemble_boitier_pid

<!-- AUTO: regenerated by `nurb card`. Do not hand-edit. -->
Size: 74.00 x 50.00 x 47.20 mm, 36320.2 mm3, 6 solids, 194 faces
Checks: clean
<!-- /AUTO -->

## What it is

Vue d'assemblage du `boitier_pid` et de son `couvercle_pid`, dans le même repère. Elle sert à vérifier l'orientation et l'engagement du rebord ; ce n'est pas une pièce à imprimer.

## Design notes

Le couvercle est construit à plat pour l'impression, puis tourné de 180° autour de Y, centré sur le milieu X du boîtier. Il est posé à la hauteur réelle du rebord de la cavité, puis le paramètre `open` le soulève en Z : `0` ferme l'ensemble et une valeur positive permet d'examiner l'intérieur dans le viewer.

L'assemblage emploie `use()` pour garder les deux pièces dans leurs définitions propres. Ses deux solides sont intentionnels : exporter et imprimer le boîtier et le couvercle séparément, chacun dans son orientation de conception.

## Don't

- Ne pas imprimer ou exporter l'assemblage comme une seule pièce : imprimer les deux composants séparément.
- Ne pas poser le couvercle sur `bbox.max.Z` par réflexe ; le placement est calculé depuis le sommet fonctionnel du boîtier et l'épaisseur de la plaque.
- Ne pas supprimer la rotation de 180° autour de Y ni le pivot au milieu X : le rebord doit descendre dans la cavité avec les découpes en face des corbeaux.
- Ne pas accepter une valeur `open` négative : elle ferait interférer le couvercle avec le boîtier.

## Changelog

- 2026-09-21 — Card renseignée : placement fermé/ouvert et rôle de contrôle de l'assemblage documentés. Encombrement avec `open = 10` par défaut : 60,00 × 50,00 × 40,20 mm, checks clean.

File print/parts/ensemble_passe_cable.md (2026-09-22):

# ensemble_passe_cable

<!-- AUTO: regenerated by `nurb card`. Do not hand-edit. -->
Size: 70.00 x 70.00 x 10.50 mm, 7579.1 mm3, 3 solids, 47 faces
Slivers: 3 under 1.0mm2, smallest 0.055mm2, 0 accepted
Checks: clean
<!-- /AUTO -->

## What it is

Assemblage du `passe_cable` assis dans le trou Ø16 (bride sous la tôle), de l'`ecrou_passe_cable` serré de l'autre côté, et d'une tôle 1 mm Ø16 (obstacle).

## Design notes

Origin at the hole centre. Gland is shifted down by flange + sheet so the flange bears on the sheet underside. Nut sits on the sheet top, turned over (its lead-in cone prints on the up face). Sheet is a 70x70x1 mm plate with a Ø16 hole, a size hint not a scan.

**La phase du filet est mesurée, pas devinée.** À 0° les flancs mâle/femelle s'interpénètrent de 12.5 mm3 ; le passe-câble tourné de 90° autour de Z ramène ça à 0.0. On tourne le passe-câble et pas l'écrou. Ça oriente aussi les deux alésages câbles nord-sud.

Interpénétrations mesurées à la pose finale : passe-câble/écrou 0.0 mm3.

No hinge: this is a seated clamp, not a motion. `nurb check` on the assembly does not sweep.

## Don't

- Do not treat a clean assembly check as a thread-fit coupon. Print both parts and screw them.
- Do not treat the sheet obstacle as a measured chassis scan.
- Ne pas tourner l'écrou autour de Z pour rattraper la phase : c'est le passe-câble qui la prend.

## Changelog

- 2026-08-31: `canal_angle` retiré de l'assemblage (pièce supprimée) ; le serre reste passe-câble + écrou + tôle Ø16.
- 2026-08-22: écrou retourné (amorce en haut à l'impression), passe-câble tourné de 90° pour la phase du filet.
- 2026-08-22: First assembly.

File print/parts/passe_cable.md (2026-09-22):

# passe_cable

<!-- AUTO: regenerated by `nurb card`. Do not hand-edit. -->
Size: 19.00 x 19.00 x 10.50 mm, 1770.9 mm3, 1 solid, 18 faces
Slivers: 2 under 1.0mm2, smallest 0.096mm2, 2 accepted
Checks: clean
<!-- /AUTO -->

## What it is

Passe-câble pour le trou Ø16 (ex-bouton brew) : bride Ø20 × 1.6 mm sous la tôle 1 mm, fût lisse Ø15.8 qui traverse la tôle, puis 6.5 mm de filet mâle. Deux alésages Ø5.2 traversants (câbles Ø4.8) à entraxe 6.4, symétriques par rapport à l'axe. Serrage par `ecrou_passe_cable`.

## Design notes

**Le filet est au pas 2.0, pas 1.41.** Le profil en dents de scie vient d'un presse-étoupe trouvé en ligne, dont le pas est 1.41 ; à ce pas il ne reste rien pour la crête. Le budget : flanc porteur 35° = 0.71, flanc de retour à 45° = 0.65, total 1.36 sur 1.41, donc une crête de 0.12 mm — moins d'un cordon de 0.42 et `min_wall` tire dessus. À 2.0 la crête fait 0.64 mm et les deux flancs restent pile à la limite imprimable. Conséquence assumée : mâle et femelle sont tous les deux imprimés, aucun écrou de presse-étoupe du commerce ne se visse dessus.

**Le chanfrein de pointe n'est pas cosmétique.** Sans lui le plan de coupe du filet tranche la dernière dent en plein milieu et laisse une section de 0.37 mm (`min_wall`). `barreau_filete(..., chanfrein_tete=profondeur+0.3)` termine le fût comme une vis.

**Les deux alésages câbles se percent APRÈS le chanfrein de bride.** Chanfreiner le bord de la bride sur un corps qui porte déjà les deux trous fait reconstruire le solide sans eux par OCCT : 2124 mm3 poli contre 1709 mm3 en draft, les deux Ø5.2 refermés en silence. C'est ce qui faisait que la bride sortait pleine.

Hauteur du fût au-dessus de la bride : `epaisseur_a_traverser` (2.6 mm par défaut : tôle 1.0 + fond 1.6, lisse) puis 6.5 de filet = 3.25 tours, dont 5.0 pour l'écrou et 1.5 de dégagement.

**`epaisseur_a_traverser` est la longueur dans l'axe (Z) du fût lisse, entre la bride et le début du filet.** C'était un calcul figé (`ep_tole + ep_fond`, deux constantes `measured()`) avant que `screen_assembly` n'ait besoin d'une autre longueur (traverser la paroi arrière de `screen_base` puis la tôle de la machine, pas la tôle 1 mm d'origine) : c'est le paramètre à monter pour traverser plus d'épaisseurs, ou plus épaisses.

Le fût lisse et le filet ont le même major Ø15.8, 0.2 sous le Ø16 de la tôle.

## Don't

- Ne pas revenir au pas 1.41 : la crête retombe à 0.12 mm.
- Ne pas percer les alésages câbles avant le chanfrein de bride (OCCT les referme).
- Ne pas retirer `chanfrein_tete` sur le filet mâle.
- Ne pas descendre la bride sous 1.2 mm.
- Ne pas remonter `diametre_fut` au-dessus de 15.8 sans revérifier le Ø16 de la tôle.
- Ne pas espérer qu'un écrou de presse-étoupe du commerce se visse dessus.

```toml
[part]

[accepted]
sliver = 2
```

## Changelog

- 2026-09-05: `epaisseur_a_traverser` ajouté (défaut 2.6 mm, identique à l'ancien calcul figé `tole_epaisseur + passe_cable_bride_epaisseur`) — c'était la seule dimension axiale de la pièce sans slider. `screen_assembly` l'utilise à 4.0 mm (paroi arrière `screen_base` 2 mm + tôle machine 2 mm) pour placer le passe-câble dans l'ouverture Ø16.
- 2026-08-22: filet réparé (le noyau disparaissait dans une fusion OCCT), pas 1.41→2.0, chanfrein de pointe, alésages câbles percés après le poli.
- Simplified: smooth barrel + flange + two cable bores (dropped broken V-thread).

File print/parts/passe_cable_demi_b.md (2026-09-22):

# passe_cable_demi_b

<!-- AUTO: regenerated by `nurb card`. Do not hand-edit. -->
Size: 19.00 x 9.50 x 10.50 mm, 880.8 mm3, 1 solid, 24 faces
Slivers: 1 under 1.0mm2, smallest 0.096mm2, 1 accepted
Checks: clean
<!-- /AUTO -->

## What it is

Moitié B de `passe_cable`, coupée dans le plan Y=0 qui porte les deux axes de trou câble — voir `passe_cable_demi_a` pour le principe. Se referme avec `passe_cable_demi_a` autour d'un câble déjà terminé, serrage par `ecrou_passe_cable`.

## Design notes

Mêmes notes que `passe_cable_demi_a` : A et B partagent `passe_cable_body` (system.py) et ne sont pas interchangeables (hélice non symétrique par rotation de 180°).

**`min_wall` et le sliver acceptés viennent de la coupe, pas d'un défaut de design.** Le plan Y=0 tranche le chanfrein de pointe du filet (`chanfrein_tete`) en plein milieu côté B, ce qui laisse une section de 0.75 mm au lieu du 1.00 mm nominal, et une facette de 0.1 mm2 juste à côté — tous les deux à l'extrême bout du filet (Z≈10), une zone qui ne porte pas la charge de serrage. `passe_cable_demi_a` n'a pas ce souci parce que la phase du filet côté A tombe autrement au même plan de coupe.

## Don't

- Ne pas imprimer deux fois cette pièce à la place de `passe_cable_demi_a` : le filet ne matche pas.
- Ne pas modifier les cotes ici : elles viennent de `passe_cable_body` dans `system.py`, partagé avec `passe_cable`.
- Ne pas chercher à faire disparaître le `min_wall` 0.75mm en jouant sur `profondeur_filet` ou `chanfrein_tete` : c'est un artefact de la coupe en bout de filet, accepté ci-dessous.

```toml
[part]
min_wall = 0.7

[accepted]
sliver = 1
```

## Changelog

- 2026-09-05: `epaisseur_a_traverser` ajouté (défaut 2.6 mm), suivant `passe_cable_body`/`passe_cable`. Voir la carte de `passe_cable` pour le détail.
- 2026-09-04: création, `passe_cable` fendu en deux pour se refermer autour d'un câble déjà terminé aux deux bouts. `min_wall` 0.75mm et 1 sliver acceptés (coupe en bout de filet, zone non porteuse).

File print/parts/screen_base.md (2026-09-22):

# screen_base

<!-- AUTO: regenerated by `nurb card`. Do not hand-edit. -->
Size: 130.50 x 68.87 x 100.73 mm, 93039.1 mm3, 1 solid, 199 faces
Checks: clean
<!-- /AUTO -->

```toml
[part]
material = "PLA"
min_wall = 0.6

[stress]
kg = 0.5
material = "PLA"
load = [0, 36.4, 63.7]
hold = [[0, 40, 0]]
```

## What it is

The cradle `screen_wedge` sits in, so the screen stands at `tilt` (45° by default) against
a vertical surface the base is plaqued against — the back face drops straight down from
the ridge to the floor, always. A hollow wedge box printed **fond on the bed**, empty
seen from above, with the electronics
under the screen. The wedge is not fastened to it: it slides down between two rails
onto two pins and is held by its own weight. **The wedge is also the lid**, and the
only way in. Two side panels close over its full 19.6 mm thickness and press-fit onto
`wedge_width`, hiding the USB-C openings `screen_wedge` cuts into its own border.

About **2 h 16 m and 93 g** on the A1 Mini, and it holds roughly 5300× the screen's
weight — this part is nowhere near its strength limit, see below.

## Design notes

- **Why this exists at all.** `screen_wedge` cannot be printed in one piece with its
  own support. Laid on a 60° seat the monolith gives **17 findings, 13 of them
  blocking**: 2 849.9 mm² of 60° overhang, a 107 mm bridge over 1 652.2 mm² which is
  the pocket ceiling the module fits against, a 74 mm bridge over 111.0 mm², and 8
  regions whose first layer starts in mid-air. The two constraints are exclusive: the
  seat wants 60°, the pocket and its walls want ≤ 45°. There is no compromise angle.
  Both reference designs found online split the same way — Waveshare's own is a case
  plus a separate stand, octopint is four screwed panels.
- **`backing` is the parameter, and the ridge height is computed from it.**
  `north_height = seat_height + backing·sin(tilt)`. Backing is how much of the wedge's
  77.8 mm actually lies on the slope, and it is the number with meaning: at **77.8 the
  whole wedge is backed**, so a press anywhere on the glass is pure compression into
  the slope. 63.5 backs only the touchscreen, and below that the top of the active area
  overhangs the ridge, where a **2.46 N** press rocks the screen off its seat — inside
  the range of a firm touch. `reject` guards both ends of that range.
- **Why the ridge is not a parameter.** Any two of {ridge height, tilt, backing} fix the
  third, and the ridge is the one nobody chooses on purpose. As a free number it drifted
  silently: raising `seat_height` 10 mm cut backing to 66.3 mm unless you also raised the
  ridge, and `screen_assembly`'s `tilt` slider — which passes tilt down but never passed
  a ridge height — swung backing from **95.3 mm at 45° to 69.8 mm at 75°** with nothing
  in the viewer saying so. Computed from `backing`, both sliders leave the screen's
  support alone.
- **The lip is the wedge's thickness, 19.60 mm, measured perpendicular to the seat.**
  That is what makes it flush with the glass: it hides no part of the module, whose
  own bottom bezel is 9.09 mm anyway.
- **The lip is never a full-width plate.** As a plate its underside is a 30° downward
  face over **2 470 mm²**. It lives on the side walls and on two ergots, each a solid
  triangle standing on the floor whose own underside falls at 49.7°.
- **The rebate is what stops the screen moving sideways during the slide.** Each side
  wall is a 4 mm shelf whose top lies on the seat, for the wedge's border to rest on,
  plus a 2 mm rail standing 3 mm proud of it. `channel_fit` 0.4 leaves 0.2 mm a side —
  loose on purpose, so the wedge still slides freely down onto the pins.
- **The side panels are a separate job: hiding the USB-C openings, not the slide fit.**
  `rail_height` (3 mm) only ever had to stop sideways play; `screen_wedge`'s own
  border is 19.6 mm thick, so above the rail its USB-C/UART channel openings were
  exposed straight out the side. `side_panel_depth` (19.6, the wedge's full thickness)
  closes over them, and `side_panel_fit` (−0.1mm total) is measured off `wedge_width`
  itself rather than the loose `channel_fit`, so the wedge presses into the last bit of
  its travel instead of rattling.
- **The panel follows the wedge's own back corner exactly, flush — it is not chamfered.**
  That corner reads as a sharp near-90° peak standing proud of the ridge, but cutting a
  chamfer into it there recedes the panel behind the wedge, which fills right up to
  the same corner: tried, and it opened a visible triangular gap along the join instead
  of softening anything. `screen_wedge` drops the polish chamfer on its own outer rim
  perimeter (`on_outer_rim`) for the same reason, so the two land flush with no reveal
  either side of the join. `seating()` also excludes this face's edges from polish here,
  same as the seat and lip planes.
- **The panel's outer top continues along the seat slope to the back face.** Starting
  from `ridge_out`, it advances along the unit `up` vector by
  `(north_y - ridge_out.Y) / up.Y`; its top edge therefore keeps the selected `tilt`
  (45° by default) and terminates exactly at `north_y`, above the ridge.
- **Neither the panel's inner (mating) face nor the shelf's inner face is chamfered —
  both are faces the wedge presses or rests flush against, and a bevel anywhere on
  their perimeter breaks that line.** `on_flat_face(edge, x)` excludes any edge lying
  flat on a face perpendicular to X at `±x`, used for the panel's inner face at
  `press_half` and the shelf's inner face at `channel_half - shelf_width`, rather than
  naming individual edges on either. An earlier version (`on_panel_return`) only
  targeted the ridge-return edge by checking `on_plane(edge, ridge, up)` restricted to
  that X — it missed the longer edge running from the front wall's crest up to the
  ridge, which is not one of the profile's named points but an edge the boolean union
  creates there; that one kept its chamfer and showed as a diagonal bevel band down
  the whole inner face. The same gap existed on the shelf's own inner edge, where the
  wedge's border actually lands. Checking the X-plane directly instead of guessing at
  each edge's shape catches the whole perimeter of either face in one test, including
  edges no per-edge check anticipated. The notch relief is handled separately,
  unaffected: it's still built before the panel is added, so the cut never nicks the
  panel's own face.
- **The foot pins run along the slope, not normal to it.** Along the slope they lean
  30° off vertical, so their own underside sits at 60° and prints support-free. Normal
  to the seat they would lean 60° and overhang at 30°.
- **The base is plaqued against a vertical surface**, so the back face drops straight
  down from the ridge (90° at the bottom-right corner in side view). There used to be
  a `footing` parameter for a free-standing desk version with a sloped back face, but
  it was never used — removed 2026-09-04, see Don't.
- **There is no notch relief cut.** An earlier version had one — 0.5 mm square along the
  notch line, meant as the doctrine's inside-corner relief at a load-bearing junction —
  but its box shared an exact X boundary with the rail's inner face at `channel_half`,
  and that tangency tessellated into a visible glitch at the seam once the panel's own
  inner chamfer stopped covering it (see the polish notes above and the changelog). The
  wedge's own bottom-rear edge sits on the bed in its print pose, so polish never
  touches it there and it comes out sharp regardless; nothing was actually perching on
  the corner. Removing the cut settled the glitch and dropped the part's two
  previously-accepted slivers to zero.
- **The back opening is a hexagon, not a circle, because only the roof of a
  horizontal hole overhangs.** Flat bottom and flat sides print as ordinary walls;
  only the last few millimetres closing over the top are a bridge. `back_opening_chamfer`
  (6 mm default) cuts just the top two corners at 45°, leaving a 4 mm flat top —
  short enough to bridge clean — instead of a full-width 16 mm ceiling. The bottom two
  corners stay square: nothing overhangs on the way down, so cutting them would only
  lose bearing area for no printability gain.
- **The opening's position is anchored off the base's own geometry, not fixed
  numbers.** `back_opening_from_left` is measured off the base's left edge
  (`-outer_half`, which moves with `wedge_width`/`channel_fit`/`rail_width`), and
  `back_opening_below_top` off `north_height`, the ridge — the actual top of the back
  face, not the (usually lower) front-wall crest. Both `reject` if the opening would
  run past the back face's own width or height.
- **Nothing the wedge touches is chamfered.** `seating()` pulls every edge lying on the
  seat plane or the lip plane out of the polish pass, because a 1 mm chamfer there is
  1 mm of daylight under the screen. It also excludes every edge wholly inside the
  rails/shelves from `floor` through `floor + seat_height`, keeping the whole seating
  volume sharp. Every other edge keeps its 1 mm chamfer.
- **Breaking is nowhere close either way.** `nurb stress` gives ~5300× margin and
  0.0002 mm of sag.
- **Three cable-tie rings stand off the back face's own interior side**, reusing
  `system.py`'s `anti_tirage_ns` — the same shape `boitier_ps` uses on its own
  north wall, called the same way (`toward_plus_y=False`, projecting into the
  box's interior). Centred on the magnet wells' own X (`outer_half/3`): two on
  the right-hand well's column (`cable_tie_low_z` 15mm, `cable_tie_right_high_z`
  40mm) and one lone ring on the left-hand well's column (`cable_tie_left_z`
  40mm) — raised from the shared 25mm/30mm it started at so it clears the
  magnet well's own boss, which stands off the same wall higher up.
- **The two ramped magnets slide in through a coin slot cut into the
  exterior back face, not a bore.** A round hole drilled straight into the
  ramp face is printed lying on its side (axis horizontal), which overhangs
  past 45° at its own top — same problem `straight_magnet_*`'s
  `puit_couche` solves below, but here there's no system.py helper for a
  slot, so it's built directly via a shared `ramp_magnet_well(x0)` closure
  (called once per side, so both wells can't drift apart in dimensions):
  the mouth sits on the exterior back face (`max_y`), dropped below the
  ridge (`north_height`), and the cut runs straight down-and-in at 45°
  (`-up`: both Y and Z decrease together) until `magnet_wall` of material is
  left before it would break out through the boss's *other* ramp (A→B) near
  its own peak — found by intersecting the ray with that ramp's line. The
  slot's own walls are flat planes at the ramp's angle, so nothing
  overhangs, and no edge in it is chamfered (`on_magnet_slot`, matched by
  each slot's own bounding box). The magnet ends up in the same place a
  round bore would have put it, just entered from above instead of the side.
- **The Z-drop for the slot's mouth is `magnet_cover·√2`, not
  `magnet_cover`.** The slot's top face ends up parallel to the ramp it
  stops short of (both contain X and the fixed 45° "up" direction), but a
  straight drop in Z isn't normal to that ramp — projected onto it, a
  `magnet_cover` drop only closes the gap by `magnet_cover/√2`. Dropping
  `magnet_cover·√2` in Z instead gives a true `magnet_cover`-thick skin
  there. Caught by `nurb check` at exactly the predicted 0.42mm
  (`0.6/√2`) before the fix.
- **`well_width` carries a fixed `+0.9mm` on top of `magnet_diameter + 2·magnet_wall`,
  and it exists only to keep the two magnets aligned with `screen_wedge`'s own,
  unrelated to how tightly the disc actually needs wrapping.** The coin slot
  stops against the boss's *first* ramp (A→B), which faces the open interior
  cavity, not the *second* ramp (B→C, parallel to the seat) the old round bore
  used — so the magnet's own facing direction changed with the slot redesign.
  Enlarging `well_width` grows the whole triangular boss (`ramp`/`climb` both
  scale with it), which walks the A→B intersection point diagonally until it
  lines back up with `screen_wedge`'s hardcoded `magnet_x`/`magnet_y`. Found
  by measuring both magnets' actual built positions (bounding boxes of the
  wedge's `petit_puit` cavity and the base's slot end-cap, both transformed
  into the same frame) rather than by re-deriving the geometry analytically —
  a hand-derived perpendicular-offset estimate got the wrong answer here.
  `cable_tie_left_z` dropped 40 → 37 alongside it: the bigger boss now
  reaches lower, into where that ring used to sit clear.
- `seat_height` is the room under the screen for the electronics. Because the
  ridge rises with it, depth is unchanged —
  `depth = 19.6·sin(tilt) + backing·cos(tilt)` does not mention it.
- **The ergots' underside is flat at Z=0, not tapered to a point.** Below `seat_height`
  ≈ 14 mm at the default 45° tilt, the old taper (straight from the seat point down to
  the origin) fell past 45° and needed support. A 4th polygon point at `(seat_y, 0.0)`
  squares the bottom off instead, so the ergot sits flush on the floor with no
  overhang at any `seat_height`, including 5.

- **Three ventilation openings are cut through each rail's own outer face,
  west and east, mirrored.** Two share `vent_y_fraction_2`'s Y (90% of the
  base's own Y length) — one low, at `vent_z`, one high, at `vent_z_2` —
  for convection, cool air in low and warm air out the higher one. The third
  sits alone at `vent_y_fraction_1` (80%), at `vent_z`. Each opening is
  `vent_width`×`vent_height` (2.5×8mm by default). Neither rail is a thin
  skin: from `channel_half` out to `outer_half` it's solid, filled from Z=0
  up to the rail's own raised-slope line (`rail_notch` to `rail_ridge`) —
  same as the shelf just inboard of it. A cut has to clear **both**
  (`rail_width` + `shelf_width`, 6mm) plus overcut on each end to actually
  reach the open interior instead of stopping blind partway through the
  shelf; a first pass that only overcut 4mm each side (`4·rail_width`,
  centred on the face) left the hole 2mm short of the interior.
  `vent_overcut` (2mm fixed, not a parameter) now extends the cut on both
  ends, mirrored for the east side by flipping the box's own X alignment
  (`Align.MIN`/`Align.MAX`) rather than building a second cutter shape.
  **Only the mouth rim is chamfered, not the cutter's full depth.**
  Chamfering the cutter itself before subtracting — tried first — ran the
  chamfer the cutter's whole depth, straight through the internal step
  where the rail's own profile (`rail_profile`) meets the shelf's
  (`seat_profile`, offset by `rail_height`): a concave junction, and
  `nurb check` flagged the result as `concave_cosmetic`, the one polish
  mistake the doctrine calls out by name — a cosmetic bevel on an inside
  corner prints as a feather edge and does nothing structural. Fixed by
  cutting with a plain box, then chamfering only the mouth rim afterward —
  the 4 new edges where the cutter meets the real, always-convex outer face
  at X=±outer_half (`vent_chamfer`, 0.5mm) — leaving every other edge the
  cut creates sharp. `on_vent()` excludes all of it from `polish`'s own 1mm
  pass so the two never double up. All three Y/Z positions are validated
  against the rail's own raised-slope segment (`rail_notch.Y` to
  `rail_ridge.Y`) and against `surface_z - wall` so no opening can run past
  the rail's own outer boundary.
- **A third magnet, `straight_magnet_*`, bores through the back face on a
  horizontal (lying) axis instead of the 45° ramp the other two stand on.**
  It plaques the base against an external magnetic surface, the role
  `base_pesage`'s now-removed `aimant_paroi` used to play (see that file's
  history). A round hole printed with its axis lying flat overhangs past
  45° at its own top, so the cutter is `system.py`'s `puit_couche` (the
  teardrop/"goutte" roof), not a plain cylinder — `puit_debout`'s round
  pad+cutter is for a floor-standing well, axis vertical, and doesn't apply
  here. The pad is a plain box: only the sliver of it that protrudes past
  the plain `wall` (`straight_magnet_cover + straight_magnet_height -
  wall`) is unsupported underneath, short enough to bridge. The magnet is
  pushed in from the interior — the mouth is sharp, at size for the full
  well depth, so the disc bears on the whole bore — and travels toward the
  exterior, stopping `straight_magnet_cover` short of it. Positioned at
  `straight_magnet_from_right` from the base's right edge, at the same Z as
  the back opening's centre (the leftmost feature on this face).
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

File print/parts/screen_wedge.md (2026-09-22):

# screen_wedge

<!-- AUTO: regenerated by `nurb card`. Do not hand-edit. -->
Size: 126.10 x 97.40 x 19.60 mm, 76951.5 mm3, 1 solid, 136 faces
Checks: 1 finding: 1 warn (overhang)
<!-- /AUTO -->

```toml
[part]
material = "PLA"
min_wall = 0.6
```

**PLA HT, annealed** like every part in this project (140 °C after annealing). This is
the visible one, so **the top face is ironed** — the finish is the reason the print
settings differ here. It sits on the machine's front panel, outside the hot bay, and
carries no mains hardware. Annealing shrinks the part: check the fit-critical
dimensions (M2.5 seats, pocket, foot sockets) **after** annealing, not off the bed.

## What it is

Waveshare ESP32-S3-Touch-LCD-4.3 carrier: open rear **frame** on the bed, solid border skirt, module pocket cut straight through it. The module drops in from the front and its own four M2.5 standoffs land on four seat pads; M2.5 screws come up from under the bed face and thread into those standoffs. The skirt's own top face is the frame, level with the glass. Outer size is glass + 10 mm sides + 5 mm top/bottom.

The rear plate is a frame exactly the width of the seat pads (`rear_frame_margin` 0), notched out to the pocket wall in front of the JST connectors on the edge opposite USB-C, so the whole back of the module is reachable and every connector can be plugged perpendicular to the PCB. USB-C and UART channels punch through the outer +X face as well as the rear plate, so the plugs can be reached from the side once a wrapping base hides the skirt.

## Design notes

- Print pose: **rear plate on the bed**, solid skirt rising, **frame rim on top**. The skirt is one volume with the pocket cut through it — not a separate inner wall.
- `pocket_depth` 12.8 mm runs from the pad tops to the rim: 8.80 glass-to-PCB plus the module's own 4.00 mm standoffs. The pads carry the standoffs, not the PCB, so leaving the standoffs out of the sum puts the frame 4.3 mm below the glass.
- **Screws are M2.5×8, and the length is not a free choice.** The counterbore is `counterbore(2.9, 4.9, 2.7, seat_z)`, so the head bears at z = 2.70 and the pad top is at z = `rear_wall + seat_height` = 6.80: **4.10 mm of plastic to cross**. An M2.5×8 therefore takes **3.90 mm** of the module's 4.00 mm standoff — 1.56 × D of engagement with 0.10 mm to spare, so it clamps rather than bottoming out even if the standoff's thread is blind. M2.5×6 would give 1.90 mm (0.76 × D), under the 1 × D minimum; M2.5×10 overshoots by 2.10 mm. Nothing standard sits between 6 and 8.
- `seat_height` is **4.3, not 4.0, for that reason**: at 4.0 the crossing is 3.80 mm and an M2.5×8 wants 4.20 mm of a 4.00 mm standoff. The drawing gives the standoff's height and says nothing about its thread depth, so 4.0 was betting on a through-threaded standoff. The 0.3 mm buys the part out of that bet; it costs 0.3 mm of overall height and 1.3 % of volume.
- The channels are roofed by the PCB's own back plane (`rim_z - module_glass_to_pcb`), because the sockets hang under the board. Stopping them at the seat plane leaves them 4 mm below the sockets.
- Build order matters: **volumes, then pocket and rear opening, then the seat pads, then the channels and counterbores**. Adding the pads before the pocket cut is what made them vanish for three sessions; cutting the channels before the pads left a 0.1 mm tongue across one.
- Seat pads are rectangular and flush into the pocket corners. A round pad leaves a wedge of void against the corner too thin to print.
- **The rear plate is a frame the width of the pads, and the 1 mm of overhang it used to keep around them was retired on purpose.** The pads take their strength from the skirt: two of their four faces are fused into the pocket wall, which is 9.5 mm thick there. The doctrine's "a loaded hole earns a fastener diameter of wall" is about the **Ø2.9 bore**, and the pad already gives exactly 2.50 mm on its two free faces without the plate's help. The plate around the **Ø4.9 head pocket** carries nothing at all: the pocket runs z 0 → 2.70, *below* the shoulder the head bears on, and the loaded material is the 4.10 mm of column between that shoulder and the pad top, in pure compression, fused into the skirt. The thread is in the module's metal standoff, so the split-the-boss failure the rule guards against cannot happen here. Flush therefore leaves **1.50 mm** around the head pocket, which was already the number between z 2.50 and 2.70 where the pocket mords into the pad — flush extends an existing minimum rather than creating one. The 1 mm of overhang cost 701 mm³ for nothing. `rear_frame_margin` is the slider that buys it back, and `reject` stops it going under 1.2 mm.
- **The frame also narrowed the USB-C side strip, 16.55 → 8.50 mm, and `outer_wall` 0 then notched that strip at the two channels.** At the channels' own y the rear plate is now only the 8.25 mm inner strip (x 45.05 → 53.30); the 2.65 mm that used to sit outside the channel is gone so the openings reach the outer face. Between and around the two openings the plate still ties the skirt. Each millimetre of `rear_frame_margin` puts a millimetre straight back; `outer_wall` puts the leftover wall back. Slices clean. The number to watch if the part ever feels flexy at the plug.
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

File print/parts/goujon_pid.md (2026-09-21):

# goujon_pid

<!-- AUTO: regenerated by `nurb card`. Do not hand-edit. -->
Size: 6.00 x 6.00 x 6.60 mm, 237.6 mm3, 1 solid, 6 faces
Checks: clean
<!-- /AUTO -->

## What it is

## Design notes

## Don't

## Changelog

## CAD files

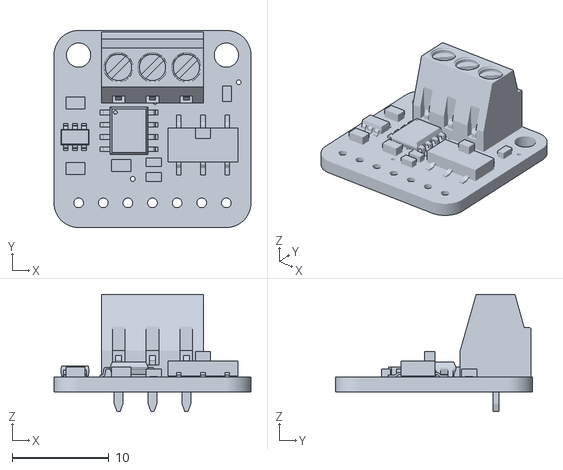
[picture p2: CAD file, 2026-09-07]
print/scans/canpal.stl
20.3 x 20.3 x 12.1

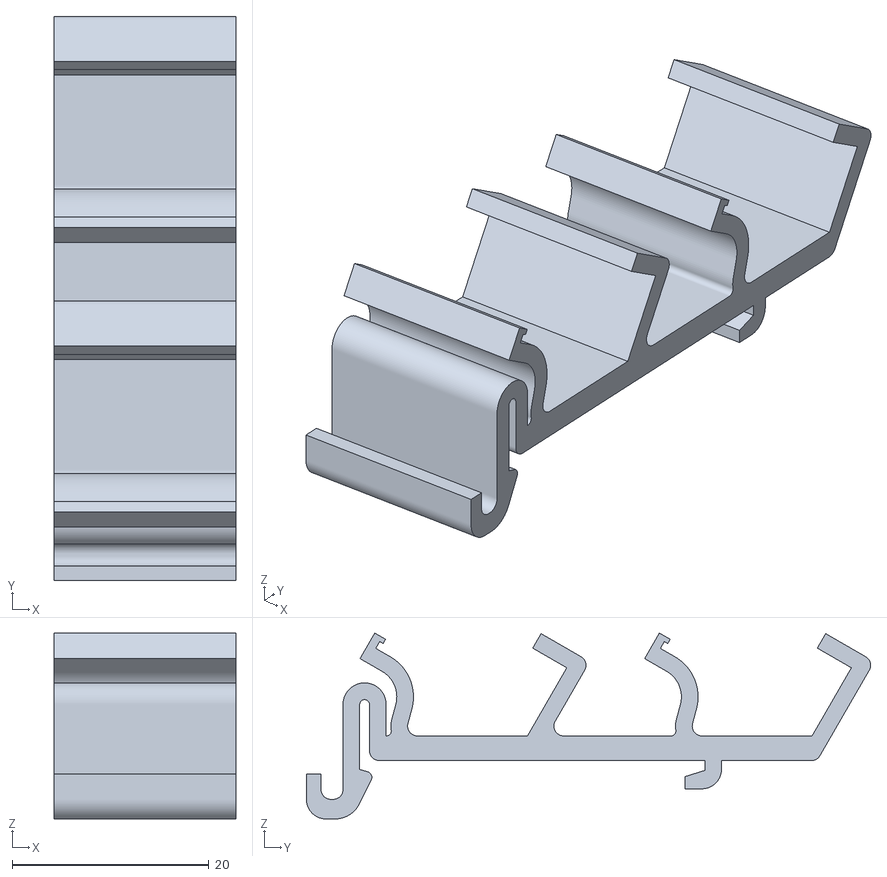
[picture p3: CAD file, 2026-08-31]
print/scans/wago3.stl
18.5 x 57.4 x 18.9

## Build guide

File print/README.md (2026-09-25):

# print/

Pièces FDM de coffeeflow. Vue d'ensemble, câblage et brochage : `../README.md` et `../docs/cablage.md`.

Cinq boîtiers autour de la machine :

- **`boitier_ps`** — alimentation RECOM et Wago 230 V, intérieur, face ouest le long du réservoir
- **`boitier_dc`** — XIAO ESP32-S3 + Grove Shield, M5Stack Unit CAN Bus, Wago 5 V ; intérieur, zone froide entre le module PID et le cadran manomètre
- **`boitier_ac`** — dimmer 4 A DimmerLink et M5Stack Unit SSR ; accolé au DC
- **`boitier_pid`** — HW-399 et Wago 5 V / GND pour commander le SSR de chaudière fourni avec la machine
- **UI** — `screen_wedge` + `screen_base`, façade, écran Waveshare 4,3", ADS1115 et sonde NTC chaudière ; l'emplacement prévu pour le LDO AMS1117 est inutilisé depuis le raccordement du pont NTC au port Sensor AD

`boitier_dc` et `boitier_ac` sont **côte à côte et reliés par un couvercle commun** (`couvercle_acdc`) ; l'assemblage des deux bacs est `ensemble_boitiers`.

nurb sert **ce** dossier (un projet nurb est un répertoire qui contient `parts/`) :

```
cd print
nurb dev          # http://127.0.0.1:7373
nurb export canal
```

**Python :** sur cette machine, préférer **`uv`** (`uv run …`, `uv run --with nurb …`). Le binaire système `python` / `python3` n’est pas fiable ici ; `nurb` lui-même est installé via `uv tool install nurb` et reste sur le PATH.

**Export :** format préféré **3MF** (`printer.toml` → `[export] formats = ["3mf"]`). Bambu Studio peut avertir sur la version 1.41 du 3MF nurb ; l’objet s’importe quand même. STL uniquement si besoin (`nurb export … --formats stl`).

## Les objets

| Fichier | Rôle |
| --- | --- |
| `parts/boitier_ps.py` | Bac de l'alimentation (RECOM, Wago 230 V, Wago 5 V) |
| `parts/couvercle_ps.py` | Couvercle du bac alimentation |
| `parts/boitier_dc.py` | Bac intérieur ouest : XIAO + Shield, Unit CAN Bus, Wago 5 V |
| `parts/boitier_ac.py` | Bac intérieur est : dimmer et SSR |
| `parts/boitier_pid.py` / `parts/couvercle_pid.py` | Boîtier du HW-399 et des Wago 5 V / GND, et son couvercle |
| `parts/ensemble_boitier_pid.py` | Assemblage du boîtier PID et de son couvercle |
| `parts/couvercle_acdc.py` | Couvercle unique des deux bacs |
| `parts/ensemble_boitiers.py` | Assemblage DC + AC |
| `parts/passe_cable.py` | Passe-câble fileté pour le trou Ø16 de l'ex-bouton brew (câble CAN) |
| `parts/ecrou_passe_cable.py` | Écrou SW22 du passe-câble |
| `parts/ensemble_passe_cable.py` | Assemblage passe-câble + écrou + tôle Ø16 |
| `parts/screen_wedge.py` | Cadre de l'écran Waveshare (vis M2.5 à l'arrière) |
| `parts/screen_base.py` | Berceau du wedge |
| `parts/screen_assembly.py` | Assemblage wedge + base |
| `parts/canal.py` | Goulotte de guidage des fils |
| `parts/goujon_indexage.py` | Pesée drip tray — **en pause** (le poids vient d'une Acaia Lunar en BLE). Cotes : `../docs/driptray.md` |
| `measurements.toml` | Cotes (Wago, aimants, Helutherm, M3, modules) |
| `printer.toml` | A1 Mini |
| `system.py` | Filet imprimable, puits d'aimant couchés, ouvertures des modules |

Vers la façade : **câble CAN** (paire torsadée orange/gris) par le trou **Ø 16 mm** de l'ancien bouton brew, avec `passe_cable` ; la sonde NTC de chaudière rejoint le boîtier de l'écran voisin. Le 5 V de l'écran vient de `boitier_ps` par un bornier adaptateur USB-C. Le 230 V ne quitte pas le compartiment technique. Détail du pont NTC : [`docs/ntc_ads1115_calibration.md`](../docs/ntc_ads1115_calibration.md).

Encombrements machine : `../docs/profitec_go.html`.

## Matière

**PLA HT recuit** pour les boîtiers : après recuit, la tenue en température monte à **140 °C**, très au-dessus des 40–50 °C du compartiment technique, et sans le fluage du PLA standard dès ~45 °C. La machine tourne 10–15 min, deux fois par jour, et reste à l'ambiante le reste du temps.

Le recuit **retire les pièces** : vérifier les cotes fit-critiques (puits d'aimant, logements Wago, inserts, filet du passe-câble) **après** recuit, pas sur la pièce sortie du plateau.

`screen_wedge` est la pièce visible : l'*ironing* de sa face supérieure est la raison de son réglage à part.

`printer.toml` déclare `material = "pla"` ; toutes les cartes de pièces sont alignées dessus. Il n'y a plus de PETG dans le projet.

## Wago et visserie

Côté machine : FASTON 6,3 × 0,8 mm isolées nylon. Côté mod : Wago 221 (412 / 415 / 423). Pas de piggyback.

- Vis **M3×10** classique (trou pilote 2,6 mm) ; **M2.5×8** pour l'écran dans le wedge
- Inserts laiton **M2.5×4** et **M3** (stock atelier) pour le montage des cartes
- Aimants **8 × 3 mm**, fond de puits 0,6 mm
- Helutherm 145 : **0,75 mm²** pour les ajouts 230 V pompe/vanne/alimentation (paires L/N sous gaine thermo), **0,25 mm²** en 5 V / signaux / CAN ; câblage de puissance chaudière : **1 mm²**

## Atelier

Bambu Lab A1 Mini. Sécher le filament avant une pièce visible (le stringing se voit).

Contraintes d'une pièce : sa carte `parts/<nom>.md` (`## Don't`), pas un `docs/` à part.

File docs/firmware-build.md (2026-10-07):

# Firmware — build, flash et banc

Conception, protocole, sécurité et mise à jour : `firmware.md`. Ce fichier
tient ce qu'il faut pour construire, flasher et reprendre le banc, ainsi que
les pièges matériels déjà payés une fois.

## Environnement

Chaque nouveau terminal doit charger ESP-IDF 6.1 :

```sh
source ~/.espressif/tools/activate_idf_v6.1.sh
```

Construire depuis le répertoire du projet concerné (`firmware/screen`,
`firmware/sensors`…) :

```sh
idf.py build
```

`idf.py build` imprime une ligne par fichier compilé (souvent plusieurs
milliers). Pour ne garder que les erreurs et le résultat final, rediriger vers
un fichier puis filtrer, sans perdre le code de sortie réel :

```sh
idf.py build > /tmp/build.log 2>&1; ec=$?
grep -iE 'error|failed' /tmp/build.log
tail -n 10 /tmp/build.log
```

Tests hôte, sans matériel :

```sh
firmware/common/test/run_tests.sh   # protocole commun, C++
firmware/tools/test/run_tests.sh    # outils Python, régénère d'abord log_codes.py
```

La table des codes `LOG` est générée depuis une source unique,
`firmware/common/codegen/log_codes.yaml` ; ne jamais éditer les fichiers
générés.

## Flash

Identifier les ports avec `esptool.py --port <port> flash-id` : le XIAO a 8 Mo
de flash et l'écran 16 Mo.

**Le flash USB direct (`idf.py flash`) est réservé à l'écriture ou à la
récupération de l'image `factory`.** Il réécrit la table de partitions, NVS
et/ou `factory` selon la configuration locale. En exploitation, les deux
cartes sont livrées par OTA, soit par HTTP en mode Wi-Fi (voir « Mise à
jour » dans `firmware.md`), soit par le pont USB↔CAN de l'écran :

```sh
cd firmware/tools
python -m coffeetool.cli flash \
  --port /dev/cu.wchusbserialXXXX \
  --dest screen ../screen/build/screen.bin
```

Avec le rythme CAN volontairement limité à 2 ms par trame, l'image écran
d'environ 1,2 Mo prend environ huit minutes (632 blocs de 2 ko). Ne pas
interrompre le pont ni l'alimentation pendant ce transfert. La confirmation
finale puis le PING/PONG au redémarrage valident l'image `PENDING_VERIFY` ;
en l'absence de validation, l'image précédente revient.

### Images factory

Les images de secours des deux cartes sont figées au commit `451566c`
(`v0.2.9`) et archivées, avec leurs SHA-256 et leur procédure, sous
`firmware/factory-images/2026-09-09-451566c/`. Elles sont à l'offset
`0x20000` de leurs partitions `factory`. L'écran factory est le pont USB↔CAN :
il sait reflasher l'écran localement et le XIAO à travers le CAN. Son écran
noir est normal, puisque cette image ne porte pas LVGL.

### Banc LCD jetable

`firmware/screen-lcd-test` (sans CAN ni NVS applicative) peut être écrit par
`idf.py flash` complet. Sa table de partitions n'est pas celle de production
(`factory` 1408 KiB contre 1000 KiB). Après usage, restaurer la table et la
factory de l'écran par `esptool.py`, jamais par `idf.py flash` :

```sh
esptool.py --chip esp32s3 --port /dev/cu.wchusbserialXXXX write_flash \
  0x8000 firmware/screen/build/partition_table/partition-table.bin \
  0x20000 firmware/factory-images/2026-09-09-451566c/screen-factory.bin
esptool.py --chip esp32s3 --port /dev/cu.wchusbserialXXXX \
  erase_region 0x10000 0x2000
```

Le second ordre efface seulement `otadata` : le bootloader choisit alors la
partition `factory`, d'où l'on relivre l'image fonctionnelle par OTA. Le même
effacement de `otadata` sert de récupération quand une image OTA redémarre en
boucle sans que le rollback reprenne le slot précédent.

### Sonde SCACE

`firmware/scace` tourne sur un M5Stack Core2 indépendant de la machine :
cible `esp32`, partition unique, sans OTA. `idf.py flash` complet est le
chemin normal. Conception et calibration : [sonde-scace.md](sonde-scace.md).

### Outils hôte

Les outils de protocole sont sous `firmware/tools/coffeetool` et s'exécutent
avec `python -m coffeetool.cli ...` (`monitor`, `send`, `record`, `replay`,
`flash`). Un seul processus peut ouvrir un port série à la fois ; le moniteur
peut afficher les trames avec retard lorsqu'il rattrape un buffer important.
`coffeetool monitor --ws … --token …` (ou `COFFEEFLOW_HTTP_TOKEN`) lit le
miroir WebSocket en mode Wi-Fi avec le même décodeur.

## Reprise du banc

1. Vérifier `CAN OK`, pression/température et débit au repos sur l'écran.
2. Vérifier les compteurs TWAI et un PING/PONG via `coffeetool` avant tout test
   applicatif.
3. Faire les essais SSR et dimmer sous 230 V avec une charge de test adaptée
   et les précautions décrites dans `firmware.md`.
4. Ne pas confondre validité du XDB401 et présence du XIAO : le premier enlève
   seulement les mesures de pression/température ; le second produit `CAN
   PERDU` après environ 3 s.

## Pièges connus

### Écran

- **Registre de sortie du CH422G.** Il est partagé entre `CAN_SEL`/`USB_SEL`
  (EXIO5), `LCD_BL`, `LCD_RST`, `TP_RST` et `SD_CS`. Il est maintenu en RAM et
  modifié uniquement par `ch422g_set_bit()` : une écriture directe (celle de
  l'exemple Waveshare par exemple) écrase les autres bits et coupe le
  transceiver CAN au moment d'allumer la dalle.
- **Timings du panneau RGB.** HSYNC `48/88/40`, VSYNC `3/32/13`, PCLK 16 MHz.
  À 12 MHz, la dalle boucle sur des mires de couleur.
- **Affinité des cœurs.** LCD et LVGL sur le cœur 1, CAN, UART, pont, Wi-Fi et
  BLE sur le cœur 0. C'est une contrainte, pas une optimisation : ailleurs,
  l'image saute. Ne pas activer `CONFIG_LCD_RGB_RESTART_IN_VSYNC`, qui
  provoquait aussi des sauts. Le décalage d'image au boot est suivi dans
  `screen-issue.md`.
- **Ordre d'initialisation.** `service_screen::init()` (cœur 1) avant
  `net_wifi::init()` (cœur 0) : les bounce buffers DMA du panneau doivent
  être alloués avant la pile Wi-Fi, sinon
  `lcd_rgb_panel_alloc_frame_buffers: no mem for bounce buffer` et reboot en
  boucle (image `v0.2.22`).
- **DIRAM.** Lier le contrôleur BLE coûte environ 18 Kio d'IRAM, même sans
  l'initialiser ; le second bounce buffer de 64 000 octets échouait alors dans
  `esp_lcd_new_rgb_panel()`. D'où `CONFIG_ESP_WIFI_IRAM_OPT=n`,
  `CONFIG_ESP_WIFI_RX_IRAM_OPT=n` et `CONFIG_BT_NIMBLE_LOW_SPEED_MODE=y`. Un
  `ESP_ERROR_CHECK` qui échoue avec la console texte désactivée ne laisse
  qu'un `Saved PC` sur `esp_cpu_wait_for_intr()` de l'autre cœur : chercher
  la cause dans les trames `LCD_INIT_STEP` du pont.
- **Polices LVGL.** `LV_USE_FONT_COMPRESSED` doit rester activé : sans lui,
  les étiquettes sont invisibles alors que les formes s'affichent. Le signe
  moins Unicode n'est pas dans les polices : utiliser le tiret ASCII.

### Radio

- Wi-Fi et BLE sont exclusifs (voir « Politique radio » dans `firmware.md`) :
  `BLE_INIT: Malloc failed` signale qu'ils ont été chargés ensemble.
- Une Lunar peut répartir l'UUID de service et le nom entre l'advertising et
  la scan response : le scan ne doit pas dédupliquer les paquets.
- Annuler le scan avant `ble_gap_connect()`, sinon la séquence
  `BLE_SCALE_FOUND` / `BLE_SCAN_STARTED` se répète. Passer `nullptr` pour les
  paramètres de connexion par défaut.
- La confidentialité NimBLE reste désactivée : inutile au client central, elle
  produisait des avertissements IRK `rc=8`.

### Module capteurs

- **UART.** Une entrée restée sur sa fonction IOMUX ne reçoit rien : forcer le
  pad en GPIO et activer son entrée après `uart_set_pin()`. Les lectures UART
  emploient des délais courts, jamais `portMAX_DELAY`.
- **XDB401.** Lire pression et température en deux transactions séparées ;
  une lecture groupée donne des pressions incohérentes. Appliquer la formule
  du fabricant à l'ordre big-endian des registres, même si le PDU est
  little-endian. Ne pas garder le mutex I2C pendant les 50 ms de conversion.
- **Pull-ups I2C.** Elles sont dans le XDB401 : le débrancher peut aussi
  rendre le dimmer muet.
- **Digmesa.** GPIO44 (D7) compte les fronts descendants, pull-up interne
  désactivé, le filtre RC assurant la polarisation. C'est aussi l'entrée
  UART0 par défaut : le forcer en GPIO. Un comptage nul persistant venait
  d'un câble inversant VCC et SIGNAL (câblage final dans `cablage.md`).
- **Dimmer.** Il lui faut le secteur pour devenir prêt : sans 230 V, son
  erreur de calibration est normale. Les flags viennent de `STATUS`
  (READY/ERROR), pas du seul registre `ERROR` ; `AC_FREQ` est informatif. Ne
  pas envoyer `RECALIBRATE` au boot. Une inversion phase/neutre sur son
  bornier a déjà été corrigée une fois. Registres : `dimmerlink-i2c.md`.

### OTA

- Un rollback n'est validé qu'avec une image réellement cassée.
- Après une erreur CRC de bloc côté `sensors`, une retransmission n'est pas
  distinguée explicitement d'un bloc suivant. Le CRC32 final protège l'image ;
  corriger ce point avant tout transport moins fiable qu'un CAN de banc.
- Le `PONG` est l'identité et la version observables d'une carte en boîte.

## Observations ouvertes

- **L2 « module interne injoignable » après un flash** (2026-09-11). Un
  redémarrage de l'écran ou des capteurs l'a levé. Un démarrage propre montre
  PING, `PRESENCE_RESTORED`, PONG et les trois `STATUS_*` avant le premier
  `LCD_INIT_STEP`. Si le cas revient, conserver le log `coffeetool monitor`
  depuis le boot : présence non relancée, trames perdues, ou rendu L2 figé
  malgré une présence restaurée.
- **Perte de synchronisation RGB pendant un flash HTTP** (2026-09-11). Elle
  revient parfois seulement au rendu du L2 « mise à jour ». Piste : latence
  entre l'ISR LCD (cœur 1) et la pile Wi-Fi/httpd (cœur 0).

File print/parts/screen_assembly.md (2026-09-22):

# screen_assembly

<!-- AUTO: regenerated by `nurb card`. Do not hand-edit. -->
Size: 140.50 x 77.17 x 100.73 mm, 201157.5 mm3, 5 solids, 396 faces
Slivers: 3 under 1.0mm2, smallest 0.055mm2, 0 accepted
Checks: clean
<!-- /AUTO -->

## What it is

`screen_wedge` seated in `screen_base`. Both parts print flat and separately; this is
the only place the fit between them is checked. The wedge's rear plate lands on the
base's seat slope, its bottom face against the lip, its borders between the two rails,
and the base's two foot pins enter the wedge's sockets.

`slide` walks the wedge back up the slope so the joint is visible in the viewer.
Everything is home at 0, and that is how it checks.

Assembled at the default `tilt` 45°, matching `screen_base`'s own default.

## Design notes

- **The number this file exists to produce**: interpenetration between the two built
  solids is **0.000 mm³** at `slide = 0`. The wedge spans x ±63.05 inside rails whose
  inner faces sit at ±63.25, so 0.2 mm a side.
- The wedge is placed by a plane rather than by Euler angles: `Plane(origin=notch,
  x_dir=(1,0,0), z_dir=n)` has its own y running up the slope, so the wedge goes in at
  local `(0, wedge_length/2 + slide, 0)` and nothing has to be reasoned about twice.
- **Assembly floats arrive wrapped.** The runtime hands an `@assembly` its float
  arguments as a float subclass so the viewer can tie a slider to a hinge, and that
  wrapper does not survive being passed into `use()`. Hence the three `float()` calls
  at the top. Without them the build dies with
  `_Named.__new__() missing 1 required positional argument: 'param'`.
- `tilt` and `seat_height` are passed down to `screen_base` so the assembly cannot show
  a geometry the parts do not have. The wedge takes neither: it is the same part at
  every angle.
- The module is an `obstacle`, a plain box at its drawing size, glass flush with the
  pocket rim. It is there to show what fills the pocket, not to check anything.
- **`passe_cable` and `ecrou_passe_cable` are placed in the 16mm back opening**, gated
  behind `show_machine_face` (and `show_cable_gland`) since sizing the gland needs
  `machine_face_thickness`. The flange sits inside `screen_base`, against the back
  wall's own interior face (`north_y - back_wall_thickness`); the smooth barrel is
  sized with `epaisseur_a_traverser = back_wall_thickness + machine_face_thickness`
  (4mm: the 2mm back wall plus the 2mm machine panel, flush against each other with
  no gap) so the thread only starts once it has cleared both. `back_wall_thickness`
  (2.0) is a literal here matching `screen_base`'s own `wall` default, not derived —
  same pattern as `wedge_thickness` above.
- **The nut is screwed all the way down against the panel's inner face**, at
  `thread_start + ecrou_epaisseur` along the gland's own axis (`thread_start =
  bride_epaisseur + epaisseur_a_traverser`), consuming the first 5mm of the 6.5mm of
  thread and leaving `ecrou_passe_cable`'s own 1.5mm `amorce_entree` clearance
  exposed past it — the same split `passe_cable`'s own card documents (its 6.5mm
  filet is deliberately `ep_ecrou + amorce`, not a round number).
- **The 90° Z rotation on the gland is required for the thread to mate**, carried
  over from `ensemble_passe_cable` where it was measured (0.0mm³ interpenetration at
  90°, 12.5mm³ at 0°) rather than guessed; the nut gets no matching Z rotation, only
  the 180° flip about X so its lead-in cone faces the gland instead of the machine's
  interior.
- **`goujon_indexage` stops `screen_base` spinning about the gland's axis**, placed
  in the second (6x6mm square) opening 20mm to the right, since the far magnet alone
  doesn't grip hard enough to resist rotation. No Z rotation needed placing it — a
  square is unchanged by a 90° turn about its own axis, unlike the gland. `cle_longueur`
  and `fut_longueur` are overridden off `back_wall_thickness`/`machine_face_thickness`
  the same way `epaisseur_a_traverser` is for the gland, so both stay correct if either
  slider moves.

## Don't

- **Don't return the wedge pre-rotated from `screen_wedge`.** It is modelled rear-plate
  down because that is how it prints. The rotation belongs here.
- **Don't reintroduce `border_tb`, `cavity_depth` or `frame_th`.** They were hard-coded
  copies of `screen_wedge`'s numbers that drifted: `border_tb` was still 10.0 after the
  wedge went to 5.0, and the other two were left over from a frame plate that no longer
  exists. The wedge placed fine anyway because the old code leaned on its bounding box,
  which is exactly why the drift went unnoticed and the ghost module sat in the wrong
  place. Derive from `measured()` or pass parameters down.
- **Don't add a hinge.** Nothing here rotates. The wedge lifts straight out along the
  seat normal, and `slide` is a translation, not a joint.
- **Don't place a hole with `Pos(x, y, z) * Plane.XZ * Cylinder(...)` and expect
  (x, y, z) to land in world space.** Tried for the machine-face plate's two
  circles: `Plane.XZ`'s own axes permute the incoming `Pos` offset (z and y swap,
  one sign-flipped), so a Pos meant to put the hole's centre at world (ox,
  north_y, oz) actually put it somewhere else entirely, and the boolean cut still
  "succeeded" (right volume removed, wrong place) rather than erroring — the kind
  of bug `nurb check` cannot see. Build an explicit `Plane(origin=(ox, north_y,
  oz), x_dir=(1, 0, 0), z_dir=(0, 1, 0))` instead, the way `screen_base`'s own
  `straight_magnet_plane` does it, and confirm the cylinder's bounding box before
  trusting it.
- **Don't skip returning an `obstacle()`'d solid.** It is only added to the
  scene from what the function actually returns (`_flatten(result)`), same as a
  hinge — building it and calling `obstacle()` on it is not enough. The machine
  face plate is returned as `base + placed, plate`, a tuple, when
  `show_machine_face` is on.

## Changelog

- 2026-09-10: sibling magnet wells now sized from `measurements.toml`
  (`small_magnet_well_cutter` / `add_well`); this assembly has no well sliders
  of its own. AUTO refreshed (faces 349 → 390).
- 2026-09-05: `goujon_indexage` (new part) placed in the 6x6mm second opening,
  20mm right of the cable gland, to stop `screen_base` rotating about the gland's
  axis — the far magnet's own friction isn't enough on its own.
- 2026-09-05: `passe_cable`/`ecrou_passe_cable` placed in the 16mm back opening,
  behind a new `show_cable_gland` toggle. `passe_cable` gained
  `epaisseur_a_traverser` (system.py's `passe_cable_body`) so its axial length is a
  parameter instead of a fixed `measured()` sum — it had no slider for its own Z
  length before this. Set here to 4mm (2mm `screen_base` back wall + 2mm machine
  panel) instead of the part's own 2.6mm default (1mm sheet + 1.6mm fond), since
  neither wall this crosses is the sheet metal the default was sized for.
- 2026-09-04: default `seat_height` 30 → 5, matching `screen_base`'s own default
  changed earlier the same day. Same stale-default bug as the `tilt` fix below —
  this one also matters now because `screen_wedge`'s new magnet wells are
  calibrated to `screen_base`'s defaults (see that card): at `seat_height` 30
  the two parts' wells no longer line up.
- 2026-09-04: default `tilt` 60° → 45°, matching `screen_base`'s own default changed
  earlier the same day. Left stale, the assembly opened on a stance neither part
  actually defaults to.
- 2026-08-17: rewritten around `screen_base`. Places the wedge on the cradle's slope,
  checks the fit (0.000 mm³ of interpenetration), and drops the stale hard-coded
  constants. Adds `slide` so the joint can be opened in the viewer.
- 2026-08-16: first cut, wedge alone stood at 60°, base out of scope.

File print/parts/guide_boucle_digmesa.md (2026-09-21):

# Guide de boucle Digmesa

<!-- AUTO: regenerated by `nurb card`. Do not hand-edit. -->
Size: 58.75 x 29.50 x 25.00 mm, 4042.9 mm3, 1 solid, 28 faces
Checks: clean
<!-- /AUTO -->

## What it is

Guide indépendant proposé, deux segments Ø8 côte à côte dans un ovale 21 × 10,5.
Une M6 dans le trou (143,23) du fond ; `distance_trou` 25 mm jusqu'à l'extrémité.
Implantation côté pompe à confirmer.

## Design notes

Chaque extrémité de l'ovale a un diamètre 10,5 : 2,5 mm de jeu sur le tube Ø8.
Entraxe des deux segments au repos 10,5 mm. Pas de serrage du silicone.
Impression couché sur la face de l'œillet, trou ovale vertical sur le plateau.
`distance_trou` (défaut 25, plancher 13) place le centre du trou M6 par rapport
à l'extrémité de la pièce : `trou_cx = 13 − distance_trou`. Semelle de 2 mm
étendue jusqu'à ce trou ; deux rainures sous la base évacuent l'eau latéralement.
La colonne sous l'œillet descend à Z=0 (plus un palier à Z=5). La vis occupe un
trou de la trame. Aucun nouveau perçage. Le trou (143,23) est une proposition
sur la trame connue, pas un montage validé.
Une seule vis exige rondelle et serrage ; résistance à la rotation à essayer.
Le guide supprime la liaison rigide directe au support du Digmesa, mais la tôle
reste une voie possible de transmission vibratoire. Valider tube au repos libre,
avec débattement, et pompe en fonctionnement ; le jeu n'est pas une garantie.

## Don't

- Ne pas réduire `distance_trou` sous 13 mm, ni le figer à 13 : 25 est le défaut,
  la semelle suit `trou_cx`.
- Ne pas relever la colonne de l'œillet à Z=5 : elle descend au plateau.
- Ne pas remettre l'implantation sur (103,23).
- Ne pas réduire le passage à un trou pour un seul segment.
- Ne pas serrer la boucle ni annoncer une isolation vibratoire garantie.
- Ne pas imprimer l'assemblage en une pièce.

## Changelog

- 2026-09-13 : `distance_trou` 25 (slider, plancher 13), semelle allongée,
  colonne d'œillet jusqu'à Z=0. Enveloppe 47,35 × 29,50 × 23 → 35 mm,
  3108,5 → 3537,5 mm3, 39 faces, checks clean.
- 2026-09-12 : proposition indépendante, ovale pour deux segments, jeu 2,5 mm.

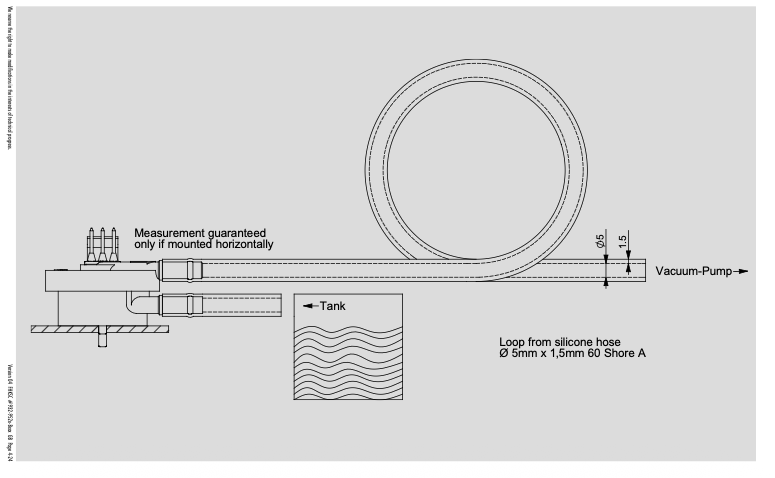
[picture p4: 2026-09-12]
docs/datasheets/digmesa-install.png

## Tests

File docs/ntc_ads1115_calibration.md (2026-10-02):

# Calibration NTC chaudière via ADS1115

> Remplacement prévu : PT1000 iOVEO 012EF02202, G 1/8, immersion inox
> 9 × 5,5 mm, deux fils silicone. Le montage ADS1115 peut être réutilisé, mais
> la conversion Beta décrite dans ce document devra être remplacée par une loi
> Callendar–Van Dusen. Avec 20 à 25 cm de câble, la résistance des deux fils
> devrait être négligeable ; elle sera simplement vérifiée à la calibration.

Le montage conservera l'ADS1115 et la résistance fixe **4,7 kΩ** déjà en
place (voir ci-dessous). Autour de 100 °C, la sensibilité
calculée restera d'environ 1,6 mV/°C, soit près de 13 codes par degré avec le
PGA ±4,096 V. Le courant de mesure sera ramené d'environ 0,92 à 0,54 mA et la
dissipation dans la PT1000 d'environ 1,2 à 0,41 mW. Un MAX31865 n'est pas
nécessaire à cette résolution. Sur la longueur prévue, une compensation des
fils n'apporterait qu'un gain négligeable. Il reste intéressant uniquement si ses diagnostics
RTD dédiés justifient une carte et une liaison SPI supplémentaires.

**Changement de résistance fixe, 2 octobre 2026.** La 4,7 kΩ du banc PT1000
(tolérance non marquée, **4676 Ω** déduits du point de glace, voir
[Essai PT1000 sur banc](#essai-pt1000-sur-banc-29-septembre-2026)) a remplacé
la 2,193 kΩ dans le pont, la NTC restant branchée.
<code>kBoilerNtcFixedOhm</code> vaut 4676 depuis l'écran 0.3.33. Les codes A1
bruts des captures antérieures se convertissent avec **2193 Ω**, les suivants
avec **4676 Ω** ; la courbe Beta et l'offset de −10 °C n'ont pas changé.
Relevés à froid, chaudière éteinte : `a0 = 26305`, `a1 = 2439`, soit
45,76 kΩ et 25,6 °C, relevé sous 0.3.32 et recalculé à la main, puis
`a0 = 26303`, `a1 = 2382` après flash de 0.3.33, soit 46,96 kΩ et 25,0 °C
lus par le firmware.

## Contexte

L'objectif est de mesurer la température de la chaudière d'une machine à
café avec la sonde NTC 1/8" déjà installée, en utilisant un ADS1115 I²C
relié à un ESP32-S3-WROOM.

L'alimentation principale est en 5 V. L'ESP32 du Waveshare est alimenté par
sa carte ; le breakout ADS1115 reçoit **3,3 V du connecteur I2C du Waveshare**.
Le pont NTC reçoit le **3V3 et le GND du port Sensor AD du même écran**.
Le LDO AMS1117 dédié au pont dans le montage initial a été retiré.

La plage utile est principalement \~80--100 °C en mode café et jusqu'à
\~120--130 °C en mode vapeur.

## Schéma de montage

Le rail 3,3 V du port Sensor AD est mesuré par A0 afin de rendre le
calcul de résistance ratiométrique. A1 mesure le point milieu du pont NTC.

``` text
Waveshare Sensor AD 3V3 ----+---- A0 ADS1115
                            |
                           NTC
                            |
                            +---- A1 ADS1115
                            |
                        R = 4.676 kΩ (2.193 kΩ avant le 2026-10-02)
                            |
Waveshare Sensor AD GND ----+---- GND proche de l'ADS1115

Waveshare I2C 3V3 / GND ---------- alimentation ADS1115
```

Notes :

-   `A0` mesure la tension réelle du 3V3 qui alimente le pont.
-   `A1` mesure la tension au point milieu NTC / résistance fixe.
-   La résistance fixe nominale est 4,7 kΩ ; sa valeur étalonnée est
    **4676 Ω**. Jusqu'au 2 octobre 2026, c'était une 2,2 kΩ mesurée à
    **2,193 kΩ**.
-   Le GPIO/AD du port Sensor n'est pas utilisé.
-   Le bas de la résistance fixe et le GND de l'ADS1115 doivent avoir une
    référence de potentiel proche. Un simple raccordement électrique entre
    deux GND éloignés ne garantit pas l'absence de chute de tension sous charge.
-   Pour mesurer directement \~3,3 V sur A0, configurer l'ADS1115 avec
    une plage compatible, typiquement **±4,096 V**.

## Calcul de la résistance NTC

Avec :

-   `R_FIXED = 4676 Ω` (2193 Ω avant le 2 octobre 2026)
-   `V_SUPPLY = tension mesurée sur A0`
-   `V_DIV = tension mesurée sur A1`

le pont est :

``` text
V_SUPPLY -> NTC -> V_DIV -> R_FIXED -> GND
```

La résistance de la NTC est donc :

``` text
R_NTC = R_FIXED * (V_SUPPLY / V_DIV - 1)
```

Si A0 et A1 sont lus avec exactement le même réglage PGA de l'ADS1115,
le rapport peut être calculé directement à partir des valeurs ADC :

``` text
R_NTC = 4676 * (ADC_A0 / ADC_A1 - 1)
```

Cela rend la mesure pratiquement indépendante de la valeur absolue du
3,3 V et de la précision absolue de la référence interne de l'ADS1115.
L'erreur de gain de l'ADS1115 s'annule dans le rapport ; restent la valeur
de `R_FIXED`, qui entre en facteur direct dans la résistance calculée, et le
GND de retour de la résistance. Une erreur de 0,1 % sur `R_FIXED` vaut environ
0,3 °C avec la PT1000 : utiliser une résistance à 0,1 %, pas le multimètre,
dont l'incertitude est plus grande que celle de la résistance.

### Correction du retour GND et vérification à froid

Le montage initial utilisait un LDO AMS1117 pour le pont et retournait le
bas de la résistance fixe au Wago GND de l'alimentation 5 V. Le GND de
l'ADS1115, amené par le port I2C du Waveshare, se trouvait **10–13 mV** au-dessus
de ce Wago sous tension. Le point milieu mesurait environ **0,143 V** par
rapport au GND de l'alimentation, mais environ **0,133 V** par rapport au GND
de l'ADS1115 ; ce dernier lisait donc correctement sa propre tension A1,
tout en surestimant la résistance de la NTC à cause de la référence GND du pont.

Le pont utilise maintenant **3V3 et GND du port Sensor AD** du Waveshare, sans
le LDO. Après modification, avec la 2,193 kΩ d'alors, un relevé `/telemetry` à froid donne
`boiler_ntc_a0_raw = 26305`, `boiler_ntc_a1_raw = 1151`, soit **3,288125 V**
sur A0, **0,143875 V** sur A1 et **47,926 kΩ** calculés. La NTC débranchée
et mesurée au multimètre juste après était à **47,9 kΩ** : l'écart est
d'environ **26 Ω**, soit **0,05 %**. Cette concordance valide la lecture
de résistance du montage corrigé à ce point froid ; elle ne valide pas à
elle seule la courbe résistance/température à chaud.

## Conversion résistance -\> température

Le modèle Beta d'une NTC est :

``` text
1/T = 1/T0 + (1/B) * ln(R/R0)
```

où :

-   `T` est la température en kelvins ;
-   `T0 = 298.15 K` pour 25 °C ;
-   `R` est la résistance NTC mesurée ;
-   `R0` est la résistance extrapolée à 25 °C ;
-   `B` est la constante Beta de la sonde.

Pour obtenir directement la température en °C :

``` text
T_C = 1 / (1/T0 + ln(R_NTC/R0)/B) - 273.15
```

### Paramètres compilés depuis 0.3.34

``` text
R0 = 47000 Ω
B  = 3930 K
T0 = 298.15 K
offset utilisateur = −10,5 °C
```

`B = 3930 K` arrondit les ajustements de l'[essai NTC sur banc](#essai-ntc-sur-banc-2-octobre-2026)
(3 916 à 3 929 K sur trois bains, 3 923 K à l'ébullition seule). À résistance
égale, la lecture sonde monte de 0,40 °C vers 90 °C, 0,51 °C vers 104 °C et
0,68 °C vers 125 °C par rapport à 3 950 K. L'offset passe de −10 à −10,5 °C
pour compenser ce décalage dans la zone d'infusion : 94 °C utilisateur
désignent la même température physique qu'en 0.3.33.

### Paramètres compilés de 0.3.9 jusqu'à l'essai du 25 septembre 2026

Les mesures directes de la sonde démontée, détaillées dans
[`chauffe-chaudiere.md`](chauffe-chaudiere.md#mesures-directes-de-la-sonde-démontée),
ont été ajustées par un modèle Beta (`R25 ≈ 47,2 kΩ`, `B ≈ 3 922 K`). Le
firmware utilisait des valeurs nominales proches de cet ajustement :

``` text
R0 = 47000 Ω
B  = 3950 K
T0 = 298.15 K
offset = 0 °C
```

Cette conversion estime la température locale de la sonde ; les points chauds,
relevés pendant le refroidissement, limitent sa précision. Avec la même
consigne enregistrée de 90 °C, la chaudière sera moins chaude qu'avec
l'ancienne courbe proche de l'affichage Gicar : 2,92 kΩ représentent environ
104 °C avec la nouvelle courbe, contre 90 °C auparavant. La consigne et les
gains de chauffe devront être validés sur la machine.

Le firmware 0.3.8 compilait l'ajustement direct `47 200 Ω / 3 922 K`. À
résistance identique, les valeurs nominales de 0.3.9 indiquent environ
0,7 °C de moins vers 90 °C et 1,2 °C de moins vers 130 °C.

L'[essai du 25 septembre 2026](chauffe-chaudiere.md)
conserve `R25 = 47 kΩ` mais porte `Beta` à **4 630 K** pour rapprocher la
cible café de l'affichage Gicar. Les valeurs ci-dessus décrivent la version
0.3.9 et les captures prises avant cet essai.

### Paramètres historiques jusqu'au firmware 0.3.7

Les mesures actuelles, en excluant volontairement l'ancienne mesure très
incertaine à \~45 °C, donnent approximativement :

``` text
R0 ≈ 27.3 kΩ @ 25 °C
B  ≈ 3730 K
```

Valeurs provisoires utilisables pour le développement :

``` text
R0 = 27290 Ω
B  = 3728 K
T0 = 298.15 K
```

Ces constantes ont été remplacées en 0.3.8 après les mesures directes de
la sonde démontée.

**Essai firmware 0.3.5 :** un décalage de `-18 °C` a été essayé pour comparer
la température en tasse ; de la vapeur est sortie pendant la purge. L'offset
est revenu à `0 °C` en 0.3.6. Les mesures de résistance et les constantes
ci-dessous n'ont pas été modifiées.

## Mesures de la NTC

Mesures effectuées manuellement sur la sonde existante de la machine :

    Température   Résistance NTC Remarque
  ------------- ---------------- ---------------------------
          29 °C         22.55 kΩ mesure basse température
          32 °C         20.78 kΩ mesure basse température
          36 °C         18.00 kΩ mesure basse température
          80 °C          3.85 kΩ
          89 °C          3.02 kΩ
          90 °C          2.89 kΩ
         100 °C          2.27 kΩ
       \~115 °C          1.48 kΩ température approximative

La mesure précédemment faite autour de 45 °C a été supprimée car sa
température était estimée à ±5 °C et elle était nettement moins fiable.

### Limites des mesures

Pour les mesures à chaud, la procédure était :

1.  lire la température entière affichée par la machine ;
2.  éteindre la machine ;
3.  débrancher la NTC ;
4.  connecter le multimètre ;
5.  mesurer sa résistance.

La chaudière peut perdre environ 0,5 °C pendant cette manipulation. La
température affichée par la machine n'a par ailleurs pas de décimales.

Les points doivent donc être considérés comme des données de calibration
expérimentales avec une incertitude non négligeable, et non comme des
références métrologiques.

## Détermination historique de la courbe Gicar

Les points situés entre 80 et 115 °C sont cohérents avec un modèle NTC
Beta proche de :

``` text
B ≈ 3728 K
R25 ≈ 27.29 kΩ
```

Une régression excluant la mesure peu fiable à \~45 °C avait donné un
résultat très proche :

``` text
B ≈ 3734 K
R25 ≈ 27.43 kΩ
```

Cette proximité indique qu'un modèle provisoire autour de :

``` text
B ≈ 3730 K
R25 ≈ 27.3 kΩ
```

est raisonnable pour commencer l'implémentation.

La résistance fixe de **2,193 kΩ** d'origine était choisie proche de la
résistance de la NTC autour de 100 °C selon cette courbe. Avec la courbe
actuelle (47 kΩ / 3950 K), la NTC vaut environ 3,3 kΩ à 100 °C et 2,85 kΩ à
105 °C : la 4676 Ω en place donne environ 180 codes/°C dans cette zone.

Une régression définitive devra comparer au minimum :

1.  le modèle Beta ;
2.  éventuellement une courbe Steinhart-Hart si elle améliore
    significativement les résidus sur la plage 25--130 °C.

## Étalonnage de la sonde en bains, avant installation

À faire avec le vrai montage `screen` (même ADS1115, même 4,7 kΩ, mêmes canaux
et même PGA, sonde au bout de rallonges sur le port Sensor AD), pas avec un
montage proto dont le retour GND serait différent. Enregistrer les **codes bruts**
`ntc_a0_raw` / `ntc_a1_raw`, pas seulement la température : le rapport
`a0/a1 − 1` vaut `R_sonde / R_fixe` et permet de recalculer l'étalonnage si
`R_fixe` change.

```sh
COFFEEFLOW_HTTP_TOKEN=… COFFEEFLOW_IP=… uv run firmware/tools/record_probe.py
```

`record_probe.py` interroge `/telemetry` à 5 Hz jusqu'à Ctrl-C et écrit
`captures/probe-<date>.json`. Plonger la sonde dans les bains pendant
l'enregistrement, puis retrouver les plateaux sur un tracé des codes. Écarter les
échantillons répétés grâce à `age_ms`. `analyze_probe.py` le fait et résume
chaque capture : moyenne, écart-type, dérive et tranches pour repérer les
plateaux, avec une fenêtre et une référence optionnelles.

```sh
uv run firmware/tools/analyze_probe.py captures/probe-….json --start 55 --end 130 --reference-c 0
```

| Bain | Rôle | Remarques |
|---|---|---|
| Glace pilée et un peu d'eau | point d'ajustement à 0 °C | remuer, sonde entièrement immergée sans toucher le fond |
| Eau bouillante | point d'ajustement | le point d'ébullition dépend de la pression locale absolue (environ −1 °C par 300 m) ; en pleine eau, sans toucher le fond |
| Eau à température ambiante, deux thermomètres | validation, pas ajustement | peu informatif sur la pente |

Pas de point vers 60 °C : l'eau refroidit en continu et la température n'est
jamais stable. Ne pas immerger la sortie des fils silicone si elle n'est pas
scellée.

Si `R_fixe` change ensuite (carte ADS1115 dédiée), refaire au moins le point à
0 °C sur la carte finie : une erreur sur `R_fixe` est un défaut de gain que ce
seul point corrige au premier ordre.

### Essai PT1000 sur banc (29 septembre 2026)

Sonde hors de la machine, sur le pont de l'écran : PT1000 entre le 3V3 du port
Sensor AD et A1, une 4,7 kΩ (tolérance non marquée) entre A1 et GND, PGA
±4,096 V. Le firmware restait réglé pour la NTC : il marquait la température
`missing`, parce que la loi Beta donne environ 179 °C pour 1,1 kΩ, au-delà de
la limite de 160 °C. Seuls les codes bruts ont servi. Conversion :
Callendar–Van Dusen IEC 60751, `R = R_fixe × (a0/a1 − 1)`.

| Capture `captures/probe-20260929-…` | Condition | Référence | Lecture (R_fixe = 4676 Ω) |
|---|---|---|---|
| `204302-235101` | air calme, 60 s | Netatmo 25,4 °C | 25,4 °C (A1 ≈ 21303) |
| `204855-502215` | eau du robinet, pointe seule | thermomètre 22,9 °C | 23,2 °C (A1 ≈ 21330) |
| `210506-779353` | glace pilée remuée, pointe seule | 0 °C (thermomètre −0,1 °C) | A1/A0 = 0,82376–0,82389 |
| `212531-670526` | ébullition, 966,1 hPa | 98,68 °C (thermomètre 100,1 °C) | 98,25–98,43 °C |

**R_fixe = 4676 Ω**, déduite du point de glace par
`R_fixe = 1000 × r / (1 − r)`, avec `r = A1/A0`. On a retenu le plateau le plus
bas, car la conduction par le corps ne peut que faire lire trop haut. Supposer
le bain à −0,1 °C donnerait 4672 Ω, soit 0,06 °C à 100 °C. Le multimètre
indique 4,68 kΩ, ce qui est cohérent, mais sa résolution ne suffit pas pour
étalonner : 10 Ω valent environ 0,8 °C à 100 °C. Avec la valeur nominale de
4700 Ω, toutes les lectures étaient trop hautes d'environ 1,5 °C.

**Point d'ébullition : −0,3 °C**, dans la tolérance de la classe B (±0,8 °C à
100 °C). La pente est donc validée sans autre correction entre 0 et 100 °C.
L'écart-type par échantillon atteint 1,1 à 1,5 °C dans l'eau bouillante, à
cause des bulles et de la turbulence, contre environ 0,2 °C en bain calme.
Le thermomètre de cuisine lit environ +1,4 °C trop haut à l'ébullition et
reste juste à 0 °C : les points fixes servent de référence, pas lui.

**Bruit à 5 Hz, bain calme :** environ 2,5 codes d'écart-type sur A1, soit
environ 0,2 °C, contre 0,8 code sur A0. Il vient donc du côté de la sonde :
captation par les fils libres ou mouvements d'air. Une moyenne sur 1 s
suffit.

**Temps de réponse.** Les durées sont mesurées depuis le début du geste
d'immersion, qui est compris dedans, pointe inox seule immergée et bain
agité à la main.

| Échelon | t63 | t90 |
|---|---|---|
| 24 °C → glace, corps à l'ambiante | ≈ 2 s | ≈ 5 s, puis traîne d'environ 40 s sur les 3 derniers °C |
| ≈ 7 °C → glace, corps encore froid | — | ≈ 8 s jusqu'au plateau |
| 24 °C → ébullition | 3,2 s | 6,7 s |
| 66 à 75 °C → ébullition, trois replongées | 2,3–2,4 s | 4,8–5,6 s |

La traîne vient du filetage resté à l'air ambiant, qui conduit la chaleur
vers la pointe. Sur la chaudière, le filetage est serré métal contre métal
et suit la température de la paroi, pas celle de l'eau : cette traîne de banc
n'y existe pas sous cette forme. En revanche, une paroi plus froide que l'eau
biaiserait la mesure vers le bas.

**Pièges constatés pendant l'essai :**

- Une sonde mouillée sortie du bain reste proche de la température de l'eau,
  parce que l'eau s'évapore à sa surface. Pour observer la reprise, il faut
  la sécher.
- Ajouter de l'eau à un bain de glace qui n'a plus assez de glace le fait
  remonter à 2–5 °C. Ce palier n'est plus un point de référence.

**Comparaison avec la NTC, décision en attente.** Chaque démontage de la sonde
sur la chaudière impose de vider la chaudière et de refaire le joint. On ne
monte donc aucune sonde à titre d'essai : on choisit sur banc, puis on monte
une seule fois. La pointe de la NTC mesure 24 mm × 3 mm de diamètre, contre 9 × 5,5 mm
pour la partie immergée de la PT1000. La NTC a été démontée le 2 octobre 2026
et passée sur le même banc, avec la même 4676 Ω que la PT1000 (voir
[Essai NTC sur banc](#essai-ntc-sur-banc-2-octobre-2026)). Le firmware n'a pas besoin de
changer, puisque les codes bruts suffisent. Repères attendus avec
`A0 ≈ 26 304` et la courbe 47 kΩ / 3950 K :

| Bain | R_NTC | A1 | Sensibilité |
|---|---:|---:|---:|
| glace | ≈ 158 kΩ | ≈ 756 codes | 39 codes/°C |
| ≈ 22 °C | ≈ 54 kΩ | ≈ 2 100 codes | 88 codes/°C |
| 100 °C | ≈ 3,3 kΩ | ≈ 15 460 codes | 181 codes/°C |

Le protocole est identique à celui de la PT1000 : même repère d'immersion
(pointe seule), sonde sèche stabilisée 2 min à l'air avant chaque échelon,
agitation similaire, au moins 90 s par bain, et une capture par bain. On
enregistre deux échelons, ambiante → glace et ambiante → ébullition, plus au
moins trois replongées depuis environ 70 °C, qui sont les échelons les plus
propres. On compare t63 et t90.

Les modèles des captures d'infusion bornent la constante propre de la NTC à
quelques secondes : le chemin eau admise → NTC ne dure que 6,4 s en moyenne,
hydraulique comprise. Les retards de régulation de 17,6 s en infusion et de
23,5 s au repos viennent surtout de la chaudière, pas de la sonde. Si la NTC
répond en moins d'environ 3 s, la PT1000 plus courte n'apporte que quelques
pourcents de retard en moins, pour le risque qu'elle touche moins bien l'eau.
Si la NTC répond en 8 s ou plus, le remplacement se justifie.

Si la PT1000 est retenue, `R_fixe = 4676 Ω` est déjà en place ; le firmware
doit passer à la loi Callendar–Van Dusen, qui s'inverse directement pour T ≥ 0 °C. Il faut
aussi retirer le décalage NTC de −10 °C
(`kBoilerNtcTemperatureOffsetC`) et le remesurer sonde montée.
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

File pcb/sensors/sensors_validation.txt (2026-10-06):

Sensors schematic validation — KiCad 10.0.6, 2026-10-01
PASS: ERC, 0 errors / 0 warnings; no exclusions added.
COUNT: 43 schematic components; 44 preliminary BOM entries. J5 remains
in the BOM but is absent from the saved schematic (pre-existing mismatch).
PASS: R1 omitted; fixed AMS1117-3.3 supports zero external load (local datasheet p. 3).
PASS: All symbol pin numbers exactly match assigned footprint pad numbers.
PASS: MCU supply and all 24 GND pads; boot/reset and flash voltage straps.
PASS: Native USB polarity, both Type-C orientations, independent CC pull-downs.
PASS: USB VBUS tied to +5V, external J1 input and AMS1117 input.
PASS: Direct USB data pair via 22-ohm resistors and ESD protection.
PASS: USB switch/detection components absent; C1 input bulk 4.7uF.
PASS: I2C GPIO5/6, two Grove pin maps, 3.3V pull-ups, TMP102 address 0x48.
PASS: CAN RX GPIO10 / TX GPIO11, TJA1051T/3 VCC/VIO/S, permanent 120-ohm termination.
PASS: Digmesa 5V supply, GPIO41 signal, 1k pull-up to 3.3V, 10nF to GND.
PASS: Valve GPIO36, 5V supply, 3.3V signal and off-state pull-down.
PASS: Boiler GPIO12 active-high, direct Q3 gate sink, P-MOS high-side topology.
PASS: Boiler gate default-off network and 1k output pull-down.
PASS: No UART service header; GPIO3/43/44 explicitly unconnected.
PDF: Two A3 pages exported and rendered for visual inspection.
Limits: schematic checks only; PCB layout is in progress. R1 removal from PCB
is pending user action. BOM LCSC sourcing, layout/DRC,
thermal checks, firmware migration and loaded hardware testing remain.

PCB DRC — KiCad 10.0.6, 2026-10-03 (saved board; zones refilled for check)
PASS: 0 physical violations, 0 unconnected items.
OPEN: 23 schematic parity warnings after PCB references were renamed and
mounting-hole PCB-only attributes reverted; see sensors_drc.json.
PASS: J2 local rounded-GND footprint, scoped 0.20mm hole clearance.
J2 restored after an editor save reverted its footprint; no DRC exclusions added.

Green status LED — KiCad 10.0.6, 2026-10-05
PASS: D2 green 0603, R25 1k 0603; GPIO38 / U1 pad34 -> R25 -> LED anode, cathode -> GND. HIGH = on.
PASS: ERC, 0 errors / 0 warnings; all previous netlist connections preserved.
PASS: GPIO38 available on MINI-1U-N8; local Espressif datasheet v1.7 Table 3-1 and section 4. No internal flash, UART, USB, JTAG or boot-strap reservation.
PDF: Two A3 pages regenerated; LED placement visually checked.
PCB: User will update placement and routing in the PCB editor.

Dual I2C / 33x70mm board — 2026-10-05
PASS: Added J5 for I2C A; J4 maps to I2C B. SCL/SDA/3V3/GND pin order identical and connected in parallel.
PASS: Existing schematic connections preserved; ERC 0 violations.
PASS: Physical DRC 0 violations / 0 unconnected items. 24 specific intentional reference/mounting parity findings accepted after independent connectivity validation.
PASS: Manufacturing archive verified: 46 components, 26 unique LCSC rows, both I2C placements at corrected pin-row centres.

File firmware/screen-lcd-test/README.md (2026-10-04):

# Diagnostic LCD / radio

Ce firmware réduit isole le démarrage de la phase 6 : CH422G, panneau RGB,
LVGL, point d'accès Wi-Fi / `httpd` minimal et hôte NimBLE. Il ne touche ni au
CAN, ni au pont, ni aux credentials ou réglages NVS CoffeeFlow.

L'image par défaut teste la séquence de production réduite :
`CH422G -> LCD/LVGL -> Wi-Fi/HTTP -> NimBLE`. La mire affiche la séquence qui
a été compilée et les logs UART annoncent chaque étape.

Dans `idf.py menuconfig`, `LCD / radio diagnostic > Sequence de demarrage
testee` sélectionne l'une des cinq images : LCD seul, LCD+Wi-Fi,
LCD+NimBLE, LCD+Wi-Fi+NimBLE, ou une alternance Wi-Fi/NimBLE toutes les cinq
secondes. Cette dernière déinitialise réellement chaque pile, contrôleur et
httpd inclus, avant d'initialiser l'autre. La première variante, sans modifier le
`sdkconfig`, se construit dans un répertoire distinct :

```sh
idf.py -B build-lcd-only -D SDKCONFIG_DEFAULTS='sdkconfig.defaults;sdkconfig.lcd-first.defaults' build
```

L'AP ouvert temporaire est `CoffeeFlow-LCD-Diag`; `GET /` retourne un statut.
Il sert seulement à faire allouer les piles réseau.

```sh
source ~/.espressif/tools/activate_idf_v6.1.sh
idf.py build
```

Ce firmware jetable se flashe directement par `idf.py -p <port> flash` sur le
banc — cycle court, sans passer par le CAN. Sa table de partitions n'est pas
celle de production : une fois le diagnostic terminé, restaurer la table de
partitions production à `0x8000`, puis l'image `factory` à `0x20000`, avant de
reprendre l'OTA normal, selon `docs/firmware-build.md`.

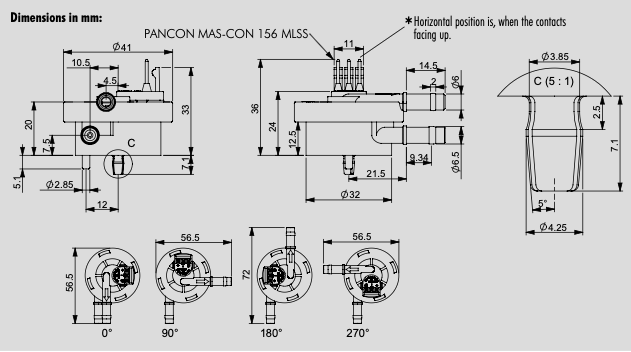
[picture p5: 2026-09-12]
docs/datasheets/digmesa-measurements.png

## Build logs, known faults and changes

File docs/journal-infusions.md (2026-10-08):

# Journal des infusions

Ce journal consigne l'analyse de chaque infusion capturée tant que le
firmware n'est pas stabilisé. Il couvre l'hydraulique (remplissage,
pré-infusion, montée, débit) autant que la chauffe. Il ne décrit pas les
lois ; il dit ce que chaque infusion a montré et ce qu'on règle ensuite.

| Sujet | Document |
| --- | --- |
| Loi de chauffe pendant l'infusion, simulation, remboursement de la précharge | [chauffe-infusion.md](chauffe-infusion.md) |
| Régulation de la chaudière, sonde, journal thermique jusqu'au 4 octobre | [chauffe-chaudiere.md](chauffe-chaudiere.md) |
| Régulation au repos | [chauffe-repos.md](chauffe-repos.md) |
| Débit libre selon la puissance de pompe, choix de remplissage et de pré-infusion | [purge_sans_resistance.html](purge_sans_resistance.html) |
| Réglages (`filling.*`, `preinfusion.*`) et règles de fin de phase | [firmware.md](firmware.md) |

Les fichiers `captures/` sont locaux et ignorés par Git.

## Réglages en cours

Configuration sauvegardée `configs/261005-075907.json` (schéma 9). Seuls le
seuil de remplissage et la puissance de pré-infusion diffèrent de
`configs/261004-142011.json`, en vigueur le 5 octobre à 7 h 26.

| Réglage | Valeur | Depuis |
| --- | --- | --- |
| Firmware écran | 0.3.40 : remboursement de la précharge, sans coupure de fin, fin de remplissage en pression absolue | avant le 5 octobre |
| Sonde de pression | XDB401 analogique sur A2 (0.3.46), loi de chauffe inchangée | 7 octobre |
| Précharge | 8 s à 90 % | 4 octobre |
| Consigne | 90 °C | — |
| Remplissage | pompe à 75 %, fin à **0,8 bar** (10 s au plus) | 5 octobre, 7 h 59 |
| Pré-infusion | pompe à **50 %**, fin à 4 s ou à la première goutte | 5 octobre, 7 h 59 |
| Infusion | pompe jusqu'à 100 %, cible 9 bar, arrêt à 22 g ou 27 s, sans ramp-down | — |

Le numéro de firmware est celui du dernier flash connu ; la capture ne
l'enregistre pas.

## Méthode

### Commandes

```sh
uv run firmware/tools/describe_hf_capture.py captures/<capture>.json
uv run firmware/tools/analyze_hf_capture.py captures/<capture>.json
uv run firmware/tools/simulate_boiler.py --capture captures/<capture>.json
```

Le rapport HTML contient, sous le graphe, une table texte par phase (durée,
volume, débit, pression, poids, NTC, commande et énergie SSR) et les
repères hydrauliques comptés depuis le début du remplissage. Ce sont les
sources des chiffres de chaque entrée. `shot_summary()` du même script
donne la durée et les débits depuis 8 bar.

### Grandeurs relevées

Toujours avec ces définitions, pour que les entrées restent comparables :

| Grandeur | Définition |
| --- | --- |
| Remplissage | durée, volume et pression de sortie de la table par phase |
| Pression de fin réelle | premier paquet au-dessus du seuil (repère « pression ≥ … ») et passage en pré-infusion ; noter l'écart |
| Pré-infusion | durée, volume, et ce qui l'a terminée : première goutte (firmware, +0,1 g) ou échéance |
| Première goutte | repère du rapport (poids ≥ 0,3 g), en temps et en volume depuis le remplissage ; le firmware déclenche plus tôt (+0,1 g) |
| Marge de remplissage | volume à la première goutte − volume à la fin du remplissage |
| Montée | temps de la fin de pré-infusion à 8 bar |
| Infusion | durée **depuis 8 bar** et débits moyens (tasse en g/s, amont en ml/s) depuis 8 bar ; la durée de la phase « infusion » (fin de pré-infusion → arrêt) est notée à part, c'est celle des tableaux de `chauffe-infusion.md` |
| Rendement | poids en tasse à l'arrêt de la pompe et poids final (gouttes comprises) |
| Thermique | NTC pondérée par la tasse (`analyze_hf_capture.py`, critère de la consigne) ; minimum pendant l'écoulement ; minimum total et son instant ; NTC à l'arrêt et 20 s après |
| Énergie | commande et SSR par phase ; l'écart entre les deux dit ce que le simulateur surestime |

### Simulation

`simulate_boiler.py` ne modélise que la NTC, sur l'hydraulique réelle de la
capture. Il ne simule ni le remplissage ni la pré-infusion : un effet de
réglage hydraulique s'estime sur la courbe pression–volume de la capture et
se présente comme une estimation.

Le modèle se trompe de 1 à 2 °C en valeur absolue (moyenne en tasse,
minimum, récupération). Ne lire que les **écarts entre variantes** rejouées
sur la même capture, et rejouer aussi avec l'énergie SSR (`heater_on`), pas
seulement la commande. Tout résultat « confirmé » doit l'être par une
mesure ; un résultat du modèle s'écrit « en simulation ».

### Rédaction d'une entrée

1. **Contexte** : capture, réglages changés depuis l'entrée précédente,
   observations de David (visuel, goût), telles quelles.
2. **Hydraulique** puis **thermique** : chiffres mesurés, comparés aux
   entrées précédentes avec les mêmes définitions.
3. **Attendus vérifiés** : reprendre un par un les attendus de l'entrée
   précédente, avec la mesure en regard. Un attendu non atteint se dit.
4. **Lecture** : causes probables, chacune marquée mesurée, estimée ou
   simulée. Une hypothèse non testée s'écrit comme telle.
5. **Décision et attendus suivants** : réglages retenus et valeurs
   attendues à la prochaine infusion, chiffrées.

Règles :

- deux réglages changés à la fois : dire quelle mesure sépare leurs effets,
  ou que rien ne les sépare ;
- ne pas reprendre un chiffre d'une autre doc sans vérifier sa définition ;
- une erreur découverte dans une entrée passée se corrige en place, avec
  une ligne « Correction du <date> » ;
- ne modifier ni le firmware ni les réglages : les décisions viennent de
  David ;
- reporter la moyenne en tasse et la capture dans les tableaux « Écart au
  critère » et « Captures de référence » de
  [chauffe-infusion.md](chauffe-infusion.md) ; changer
  [firmware.md](firmware.md) seulement si un défaut ou une règle de fin de
  phase change.

## Synthèse

Valeurs du rapport (définitions ci-dessus). Les infusions avant le
5 octobre finissaient le remplissage sur +0,1 bar au-dessus du plancher
(schéma 8) et pré-infusaient à 60 % (35 % le 4 octobre à 13 h 24).

| Infusion | Remplissage | Pré-infusion | 1re goutte | Montée à 8 bar | Depuis 8 bar | Tasse | NTC tasse |
| --- | --- | --- | ---: | ---: | --- | ---: | ---: |
| 30/09 14 h 25 | 4,05 s, 13,6 ml, 0,42 bar | 3,30 s, 11,0 ml, goutte | 24,6 ml | 5,3 s | 9,3 s, 1,47 g/s, 1,90 ml/s | 22,3 g | 89,60 °C |
| 01/10 8 h 29 | 4,40 s, 14,8 ml, 0,42 bar | 1,30 s, 4,1 ml, goutte | 18,8 ml | 6,4 s | 7,3 s, 1,59 g/s, 2,06 ml/s | 22,5 g | 88,42 °C |
| 04/10 10 h 01 | 3,00 s, 10,1 ml, 0,33 bar | 4,00 s, 12,5 ml, échéance | 38,0 ml | 4,6 s | 29,8 s, 0,71 g/s, 0,91 ml/s | 22,2 g | 92,50 °C |
| 04/10 13 h 24 | 4,50 s, 15,4 ml, 0,39 bar | 4,00 s, 2,0 ml, échéance | 35,1 ml | 6,4 s | 17,8 s, 1,10 g/s, 1,40 ml/s | 22,2 g | 87,58 °C |
| 05/10 7 h 26 | 7,00 s, 24,1 ml, 1,19 bar | 1,20 s, 1,2 ml, goutte | 25,8 ml | 4,5 s | 13,3 s, 1,28 g/s, 1,85 ml/s | 22,4 g | 88,64 °C |
| 06/10 7 h 19 | 6,10 s, 21,2 ml, 0,90 bar | 2,10 s, 4,1 ml, goutte | 25,5 ml | 4,8 s | 11,8 s, 1,35 g/s, 1,89 ml/s | 22,6 g | 88,47 °C |
| 08/10 8 h 43 | 6,30 s, 20,0 ml, 0,88 bar | 3,40 s, 6,1 ml, goutte | 26,7 ml | 4,5 s | 16,0 s, 1,07 g/s, 1,16 ml/s | 22,2 g | 87,69 °C |
| **08/10 13 h 44** | 5,80 s, 20,3 ml, 0,83 bar | 3,40 s, 6,7 ml, goutte | 27,0 ml | 4,0 s | 15,0 s, 1,15 g/s, 1,39 ml/s | 22,2 g | 88,80 °C |

## Pistes pour le goût

Recette : grain ViCafé (100 % arabica), 8,0 g en panier. Les pistes
ci-dessous attendent que la chauffe soit stabilisée ; on n'en change
qu'une à la fois. Les repères « avant » viennent du journal de dégustation
tenu avant la modification de la machine (juillet–août 2026, local, hors
Git).

| Piste | Priorité | Lecture |
| --- | --- | --- |
| Température | **première** | Les meilleurs cafés d'avant étaient à « 93 °C » affichés par la machine ; la consigne est aujourd'hui de 90 °C à la NTC, 88,8 °C en tasse le 8 octobre à 13 h 44. Les deux chiffres ne viennent pas du même capteur : il faut d'abord étalonner la SCACE pour savoir ce que « consigne 90 °C » donne dans la galette, puis seulement choisir une consigne |
| Pression | basse | Peu de marge attendue, mais une pression plus basse (≈ 8,5 bar) vaut un essai. Avant, 9 → 8 bar à débit égal avait donné de la rondeur, mais sur un grain avec 30 % de robusta ; sur le ViCafé, tous les bons cafés étaient à 9 bar. Les « 9 bar » d'avant venaient de la machine, ceux d'aujourd'hui du XDB401 (plateau à 8,87 bar). Essai à débit égal : baisser la pression ralentit le débit, ouvrir la mouture en même temps, sinon l'amertume du ralentissement se lit comme un effet de la pression |
| Poids | basse | 22 g (ratio 2,75) est le point retenu pour 8 g. Avant : ratio 2,70 à 2,85 retenu, 24 g (ratio 3,00) amer à galette impeccable. Le filet blondit déjà à 22 g. Seul ajustement possible : jusqu'à ≈ 23 g si la mouture plus grosse laisse le filet encore crémeux à 22 g, une galette rapide s'épuisant plus tard |

## Entrées

### 5 octobre, 7 h 26 — `261005-072633`

**Contexte.** Première infusion du firmware 0.3.40 : fin de remplissage à
1,0 bar absolu, sans coupure de fin de chauffe. Précharge de 8 s,
remplissage à 75 %, pré-infusion à 35 %. Mouture plus grosse que les
précédentes. Observations de David : le café était visible sous le panier
à la fin du remplissage, la première goutte est venue très tôt ; café jugé
trop rapide, mouture trop grossière.

**Hydraulique.**

| Phase | Début | Durée | Volume | Pression |
| --- | ---: | ---: | ---: | --- |
| Précharge | 0,04 s | 8,05 s | — | — |
| Remplissage | 8,09 s | 7,00 s | 24,1 ml (3,44 ml/s) | 0,39 → 1,19 bar |
| Pré-infusion | 15,09 s | 1,20 s | 1,2 ml | 1,19 → 1,00 bar |
| Infusion | 16,29 s | 17,80 s | 38,3 ml | 9,46 bar max |

- Premier paquet au-dessus de 1,0 bar à 14,99 s, passage en pré-infusion à
  15,09 s : 100 ms. [firmware.md](firmware.md) décrit une confirmation d'au
  moins 150 ms ; l'écart n'est pas expliqué (décalage de la capture ou
  description imprécise).
- La pression monte vite en fin de remplissage : 0,71 bar à 19,7 ml,
  0,85 bar à 22,0 ml, 1,10 bar à 23,8 ml, soit ≈ 0,5 bar/s.
- Le firmware a vu la première goutte à 16,29 s et 25,2 ml, et a terminé la
  pré-infusion dessus ; le rapport la place à 25,8 ml (≥ 0,3 g). Marge de
  remplissage : 1,1 à 1,7 ml selon la définition.
- La pré-infusion à 35 % ne pousse presque rien : 1,2 ml en 1,2 s ici,
  2,0 ml en 4,0 s le 4 octobre à 13 h 24. À 60 % (30 septembre au
  4 octobre à 10 h 01), elle passait 3,1 à 3,3 ml/s.
- Montée de 4,5 s jusqu'à 8 bar. La pompe passe 2 s à 100 % (≈ 18,5 à
  20,5 s), puis tient 9 bar vers 70 %.
- Depuis 8 bar : 13,3 s, 1,28 g/s en tasse, 1,85 ml/s en amont, 21,4 g à
  l'arrêt, 22,4 g final. C'est **plus lent** que les deux autres infusions
  à mouture grossière (1,47 et 1,59 g/s) et dans la fourchette de 1,4 à
  2 ml/s de [chauffe-infusion.md](chauffe-infusion.md#constats-qui-fondent-la-loi).
  Le jugement « trop rapide » de David ne se lit donc pas dans le débit
  comparé aux infusions précédentes.

**Thermique.**

| Grandeur | Mesure |
| --- | ---: |
| NTC pondérée par la tasse | **88,64 °C** (−1,36 °C) |
| NTC pondérée par le volume | 89,62 °C |
| Pic avant l'infusion | 91,58 °C |
| Minimum pendant l'écoulement | 87,40 °C, à l'arrêt de la pompe |
| Minimum total | 86,20 °C, ≈ 5 s après l'arrêt (−3,88 °C) |
| 20 s après l'arrêt (fin de la capture) | 88,30 °C, en hausse |

| Phase | Commande | SSR |
| --- | ---: | ---: |
| Précharge | 8,54 kJ | 8,28 kJ |
| Remplissage | 6,53 kJ | 5,64 kJ |
| Pré-infusion | 1,12 kJ | 1,08 kJ |
| Infusion | 3,45 kJ | 3,24 kJ |
| Récupération | 1,80 kJ | 2,28 kJ |

La commande est restée à 0 % de 16,49 à 28,89 s (remboursement de la
précharge), puis a suivi le débit à 45–62 % jusqu'à l'arrêt. Besoin estimé
de l'eau admise (64,9 ml, eau à 24,5 °C supposée) : 19,1 kJ. Le SSR a fourni
18,2 kJ de la précharge à l'arrêt, la commande 19,6 kJ. L'écart vient surtout
du remplissage : les hausses de commande attendent la fenêtre SSR suivante.

**Attendus vérifiés** (section « Prochain essai » de
[chauffe-chaudiere.md](chauffe-chaudiere.md), écrite pour 0.3.40) :

| Attendu | Mesure |
| --- | --- |
| Commande à 0 % dès l'infusion, ≈ 700 %·s retenus, puis appoint jusqu'à l'arrêt | oui : 0 % pendant 12,4 s, puis 45–62 % jusqu'à l'arrêt |
| ≈ 10 ml de plus dans le remplissage | oui : 24,1 ml contre 13,6 à 15,4 ml |
| Moyenne en tasse inchangée par la suppression de la coupure | invérifiable sans essai A/B ; en simulation, −0,03 °C avec la coupure |
| État 20 à 30 s après l'arrêt proche de la consigne ou au-dessus | **non** : 88,30 °C à +20 s, encore en hausse ; la capture s'arrête là |

**Lecture.**

- *Coupure de fin, en simulation.* La loi 0.3.38 aurait laissé la commande
  à 0 % de 16,5 s à l'arrêt : le remboursement n'était pas soldé quand la
  coupure (11 s avant l'arrêt) aurait commencé. Rejouée, elle donne la même
  moyenne en tasse (89,60 contre 89,63 °C), un minimum plus bas de 0,6 °C et
  2,3 °C de moins 20 s après l'arrêt. Le modèle se trompe de 2,4 °C sur ce
  dernier point (90,70 simulé, 88,30 mesuré) : seul le sens de l'écart est
  fiable. Pas de dépassement après l'arrêt cette fois : la coupure n'avait
  rien à corriger.
- *Baisse de 3,88 °C, décomposition estimée.* Rejouée avec la commande et
  sans chauffe après l'arrêt, la NTC simulée descend à 88,19 °C puis revient
  à 90,42 °C : le montant remboursé est bon, et ≈ 1,9 °C de baisse sont du
  transit (chauffe ≈ 17,6 s jusqu'à la sonde, eau froide ≈ 6,4 s). Avec
  l'énergie SSR, minimum à 87,25 °C et retour à 89,47 °C : ≈ 0,9 °C vient du
  SSR en retrait. Le reste, ≈ 1 °C, est le facteur que le modèle ne connaît
  pas, déjà vu à 13 h 24 (−2 °C). Piste non vérifiée : eau du réservoir sous
  24,5 °C à 7 h 26 (≈ 1,4 % de besoin en plus par kelvin).
- *Tasse froide.* Rien n'attribue les −1,36 °C au remboursement : aucune
  variante sans remboursement n'a été rejouée sur cette capture. Plus chaude
  qu'à 13 h 24 (87,58 °C), mais deux changements séparent les deux
  infusions et rien ne départage leurs effets.
- *Énergie et seuil de remplissage.* Si la dette est soldée avant l'arrêt
  (ici à 28,9 s), l'énergie totale vaut l'appoint sur toute l'eau admise,
  quelle que soit la phase où elle passe. Le seuil ne déplace alors que le
  moment de la chauffe. Cela contredit le « ≈ +2,9 kJ » attendu du seuil à
  1 bar dans [chauffe-chaudiere.md](chauffe-chaudiere.md) ; point à
  vérifier.
- *Flow profiling, en estimation.* Un plafond de 1,2 g/s en tasse aurait peu
  changé cette infusion : 1,25 à 1,35 g/s au plateau, soit un plateau vers
  8,3 bar si la galette est linéaire, et ≈ 1,5 s de plus. Il aurait surtout
  retenu la montée (1,45 g/s à 5,2 bar, pompe à 100 % pendant 2 s).
  Avec une mouture nettement plus grossière, la pression resterait basse :
  le flow profiling égalise la durée, pas l'extraction. Option à garder :
  plafond de débit sous un plafond de pression de 9 bar.

**Décision.** Remplissage gardé à 75 % : remplir lentement dégrade la
galette, qui devient perméable à faible pression ; à 70 %, le remplissage
serait 10 % plus long pour ≈ 0,1 ml de dépassement en moins (débit libre de
4,64 contre 5,12 g/s, [purge_sans_resistance.html](purge_sans_resistance.html)).
Fin de remplissage à **0,8 bar** et pré-infusion à **50 %**. Un seuil plus
bas (0,7 bar) laissait ≈ 4,9 ml de marge, que la pause à 35 % n'aurait pas
comblés : pré-infusion terminée à l'échéance. La pompe à 50 % doit pousser
la galette jusqu'à la goutte.

Les deux changements se séparent : le seuil ne touche que la fin du
remplissage, la puissance ne touche que la pré-infusion.

**Attendus pour l'infusion suivante** (estimés sur la courbe de cette
capture, même mouture supposée) :

| Point | Attendu |
| --- | --- |
| Paquet au-dessus de 0,8 bar | ≈ 21,2 ml, ≈ 6,2 s après le début du remplissage |
| Fin du remplissage | ≈ 21,5 ml, ≈ 6,3 s |
| Marge avant la première goutte | ≈ 3,7 ml (goutte à 25,2 ml selon le firmware) ; dépend de la mouture |
| Pré-infusion à 50 % | débit libre de 2,06 g/s à froid, moins sous la galette ; si elle passe 1,5 à 2,5 ml/s, la goutte tombe en 1,5 à 2,5 s et termine la pré-infusion avant l'échéance |
| Si la pré-infusion va à l'échéance | la galette retient plus d'eau qu'ici, ou 50 % ne pousse pas : relever le volume passé |
| Thermique | pas d'attendu chiffré : noter commande et SSR par phase, et la NTC 20 s après l'arrêt |

Si possible, prolonger la capture à 40–60 s après l'arrêt pour voir où la
NTC se stabilise.

### 6 octobre, 7 h 19 — `261006-071953`

**Contexte.** Premiers essais du seuil de remplissage à 0,8 bar et de la
pré-infusion à 50 % (`configs/261005-075907.json`), firmware et mouture
inchangés depuis le 5 octobre. Observations de David : débit assez élevé,
amertume en bouche ; mouture jugée trop grossière.

**Hydraulique.**

| Phase | Début | Durée | Volume | Pression |
| --- | ---: | ---: | ---: | --- |
| Précharge | 0,00 s | 8,00 s | — | — |
| Remplissage | 8,00 s | 6,10 s | 21,2 ml (3,47 ml/s) | 0,38 → 0,90 bar |
| Pré-infusion | 14,10 s | 2,10 s | 4,1 ml (1,93 ml/s) | 0,90 → 0,98 bar |
| Infusion | 16,20 s | 16,50 s | 36,8 ml | 9,07 bar max |

- Premier paquet au-dessus de 0,8 bar à 13,90 s (20,6 ml, 5,9 s après le
  début du remplissage), passage en pré-infusion à 14,10 s : 200 ms,
  compatible avec la confirmation d'au moins 150 ms de
  [firmware.md](firmware.md). Le 5 octobre, l'écart était de 100 ms.
- Le firmware a vu la première goutte à 16,20 s et 25,2 ml, comme le
  5 octobre, et a terminé la pré-infusion dessus, 1,9 s avant l'échéance ;
  le rapport la place à 25,5 ml (≥ 0,3 g). Marge de remplissage : 4,0 à
  4,3 ml selon la définition.
- Montée de 4,8 s jusqu'à 8 bar, avec 5,5 g déjà en tasse (4,4 g le
  5 octobre). Le débit en tasse culmine à 1,8 g/s vers 19,5 s, sous
  ≈ 4 bar.
- Depuis 8 bar : 11,8 s, 1,35 g/s en tasse, 1,89 ml/s en amont, 21,6 g à
  l'arrêt, 22,6 g final. Plus court et plus rapide que le 5 octobre
  (13,3 s, 1,28 g/s).
- Plateau (de 8 bar + 2 s à l'arrêt − 0,5 s) : 8,59 bar en moyenne, pompe
  à 69 %, 1,37 g/s, soit 6,3 bar·s/g contre 6,8 le 5 octobre (pompe à
  70 %). Galette ≈ 8 % moins résistante, à mouture inchangée.

**Thermique.**

| Grandeur | Mesure |
| --- | ---: |
| NTC pondérée par la tasse | **88,47 °C** (−1,53 °C) |
| NTC pondérée par le volume | 89,68 °C |
| Pic avant l'infusion | 92,03 °C |
| Minimum pendant l'écoulement | 86,74 °C, à l'arrêt de la pompe |
| Minimum total | 85,89 °C à 37,2 s, ≈ 4,4 s après l'arrêt (−3,92 °C) |
| 20 s après l'arrêt (fin de la capture) | 87,74 °C, en hausse |

| Phase | Commande | SSR |
| --- | ---: | ---: |
| Précharge | 8,64 kJ | 8,64 kJ |
| Remplissage | 5,61 kJ | 4,68 kJ |
| Pré-infusion | 1,83 kJ | 1,68 kJ |
| Infusion | 2,81 kJ | 2,76 kJ |
| Récupération | 2,43 kJ | 2,76 kJ |

La commande, à 90 % pendant le remplissage, descend de 78 à 52 % pendant
la pré-infusion, reste à 0 % de 16,20 à 27,70 s (11,5 s), puis suit le
débit à 36–57 % jusqu'à l'arrêt. De la précharge à l'arrêt : 18,9 kJ
commandés, 17,8 kJ fournis par le SSR, pour 62,3 ml admis. Comme le
5 octobre, l'écart vient surtout du remplissage.

**Attendus vérifiés** (entrée du 5 octobre) :

| Attendu | Mesure |
| --- | --- |
| Paquet au-dessus de 0,8 bar à ≈ 21,2 ml, ≈ 6,2 s | 20,6 ml, 5,9 s |
| Fin du remplissage à ≈ 21,5 ml, ≈ 6,3 s | 21,2 ml, 6,1 s |
| Marge de ≈ 3,7 ml avant la goutte (25,2 ml selon le firmware) | 4,0 ml, goutte à 25,2 ml |
| Pré-infusion à 1,5 à 2,5 ml/s, goutte en 1,5 à 2,5 s avant l'échéance | 1,93 ml/s, goutte en 2,1 s |
| Thermique : noter commande, SSR et NTC à +20 s | ci-dessus ; 87,74 °C à +20 s |
| Capture prolongée à 40–60 s après l'arrêt | **non** : 19,9 s |

**Lecture.**

- *Mouture, mesuré.* Tout désigne une galette trop perméable : débit en
  tasse de 1,8 g/s sous 4 bar pendant la montée, 5,5 g en tasse à 8 bar,
  11,8 s depuis 8 bar, résistance au plateau en baisse. La mouture est la
  même que le 5 octobre ; la différence de résistance vient de la
  préparation ou de la pré-infusion, sans mesure pour départager.
- *Pré-infusion, mesuré.* À 50 %, elle passe 4,1 ml et ne laisse pas de
  pause sans débit : la galette est mouillée jusqu'à la goutte, comme
  attendu. Qu'elle soit pour quelque chose dans la perméabilité au plateau
  reste une hypothèse non testée.
- *Amertume, hypothèse non testée.* Une mouture grossière sous-extrait et
  donne plutôt un café acide ou creux. Une amertume avec un débit élevé
  évoque une extraction inégale (canal) ou de l'astringence. La pression
  ne s'effondre pas au plateau, aucun canal franc n'est visible.
- *Pic avant l'infusion, estimé.* 92,03 °C contre 91,58 °C le 5 octobre :
  le remplissage s'arrête 2,9 ml plus tôt, donc moins d'eau froide sous la
  précharge, pour une commande identique jusque-là.
- *Tasse froide, en simulation.* Rejouée avec la commande réelle, la
  moyenne en tasse vaut 89,15 °C (0,68 °C au-dessus de la mesure), le
  minimum 87,88 °C (2,0 °C au-dessus) et le pic 90,66 °C (1,4 °C
  en dessous). Le modèle surestime le creux comme le 5 octobre ; le
  facteur inconnu reste inexpliqué.

**Décision.** David affine la mouture pour la prochaine infusion. Réglages
inchangés (`configs/261005-075907.json`), pour attribuer à la mouture seule
les écarts de la prochaine capture.

**Attendus pour l'infusion suivante** (même configuration, mouture plus
fine) :

| Point | Attendu |
| --- | --- |
| Remplissage | fin à 0,8 bar, 20 à 22 ml, ≈ 6 s ; la mouture ne change que la galette sèche, peu le remplissage |
| Pré-infusion à 50 % | moins de 1,9 ml/s ; goutte au-delà de 2,1 s, peut-être à l'échéance de 4 s (≈ 7 ml passés au plus) |
| Montée | moins de 5,5 g en tasse à 8 bar, pic de débit en tasse sous 1,8 g/s |
| Plateau | résistance au-dessus de 6,8 bar·s/g, pompe sous 69 % pour tenir 9 bar |
| Depuis 8 bar | plus de 13,3 s, moins de 1,28 g/s ; au-delà de 27 s le temps arrête la pompe avant 22 g |
| Thermique | pas d'attendu chiffré : la commande à 0 % (≈ 11,5 s ici) couvrira une part plus faible d'une infusion plus longue ; noter commande, SSR et NTC à +20 s |

Prolonger la capture à 40–60 s après l'arrêt pour voir où la NTC se
stabilise.

### 8 octobre, 8 h 43 — `261008-084342`

**Contexte.** Première infusion avec la pression lue sur le XDB401
analogique (écran 0.3.46, voir [xdb401_swap.md](xdb401_swap.md)) ; loi de
chauffe inchangée depuis 0.3.40, réglages d'infusion inchangés
(`configs/261005-075907.json`). Mouture affinée depuis le 6 octobre.
Observations de David : mouture probablement un peu trop fine, infusion
plus longue.

Le changement de sonde touche peu les comparaisons : l'analogique a son
zéro à l'atmosphère (l'I2C lisait +0,027 bar) et lit le plateau de l'OPV
0,06 bar plus haut que l'I2C.

**Hydraulique.**

| Phase | Début | Durée | Volume | Pression |
| --- | ---: | ---: | ---: | --- |
| Précharge | 0,04 s | 8,05 s | — | — |
| Remplissage | 8,09 s | 6,30 s | 20,0 ml (3,17 ml/s) | 0,48 → 0,88 bar |
| Pré-infusion | 14,38 s | 3,40 s | 6,1 ml (1,79 ml/s) | 0,88 → 1,18 bar |
| Infusion | 17,79 s | 20,40 s | 32,2 ml | 9,07 bar max |

- Pression au repos avant l'infusion : 0,44 bar piégés.
- Premier paquet au-dessus de 0,8 bar à 14,19 s (19,4 ml, 6,1 s après le
  début du remplissage), passage en pré-infusion à 14,38 s : 200 ms, comme
  le 6 octobre. La fin de remplissage sur la sonde analogique se comporte
  comme sur l'I2C.
- Le firmware a vu la première goutte à 17,79 s et 26,1 ml, 0,6 s avant
  l'échéance ; le rapport la place à 26,7 ml (≥ 0,3 g). Marge de
  remplissage : 6,1 à 6,7 ml (4,0 à 4,3 ml le 6 octobre).
- Montée de 4,5 s jusqu'à 8 bar, avec 4,1 g en tasse (5,5 g le 6 octobre).
  Débit en tasse au plus de 1,35 g/s vers 21,3 s, sous ≈ 4,7 bar.
- Depuis 8 bar : 16,0 s, 1,07 g/s en tasse, 1,16 ml/s en amont, 21,5 g à
  l'arrêt (au poids), 22,2 g final.
- Plateau (de 8 bar + 2 s à l'arrêt − 0,5 s) : 8,91 ± 0,06 bar, pompe à
  67 %, 1,08 g/s, soit **8,3 bar·s/g** contre 6,3 le 6 octobre et 6,8 le
  5 octobre : galette ≈ 30 % plus résistante qu'au 6 octobre.
- Après l'arrêt, la pression piégée tombe à 7,06 bar puis remonte à
  9,35 bar en 9 s, chaudière en chauffe (dilatation), et s'y plafonne
  (9,27 bar en fin de capture) : l'OPV limite le tronçon.

**Thermique.**

| Grandeur | Mesure |
| --- | ---: |
| NTC pondérée par la tasse | **87,69 °C** (−2,31 °C) |
| NTC pondérée par le volume | 89,28 °C |
| Pic avant l'infusion | 91,71 °C, à 13,99 s (fin du remplissage) |
| Minimum pendant l'écoulement | 85,37 °C, à l'arrêt de la pompe |
| Minimum total | 83,41 °C à 45,3 s, ≈ 7,0 s après l'arrêt (6,38 °C sous la NTC de départ, 89,79 °C) |
| 20 s après l'arrêt (fin de la capture) | 86,19 °C, en hausse |

| Phase | Commande | SSR |
| --- | ---: | ---: |
| Précharge | 8,54 kJ | 8,40 kJ |
| Remplissage | 5,45 kJ | 4,68 kJ |
| Pré-infusion | 2,45 kJ | 2,28 kJ |
| Infusion | 2,06 kJ | 2,04 kJ |
| Récupération | 6,78 kJ | 6,72 kJ |

La commande reste à 0 % de 17,89 à 33,29 s (**15,4 s**, remboursement de
712 %·s), puis suit le débit à 33–37 % pendant les 4,9 dernières secondes.
15,8 des 21,5 g en tasse arrivent pendant ce 0 %. De la précharge à
l'arrêt : 18,5 kJ commandés, 17,4 kJ fournis par le SSR, pour 58,3 ml
admis, soit 0,298 kJ/ml fournis (0,286 le 6 octobre, 0,280 le 5 octobre).

**Attendus vérifiés** (entrée du 6 octobre) :

| Attendu | Mesure |
| --- | --- |
| Remplissage : fin à 0,8 bar, 20 à 22 ml, ≈ 6 s | 20,0 ml, 6,3 s |
| Pré-infusion sous 1,9 ml/s, goutte au-delà de 2,1 s, ≈ 7 ml au plus | 1,79 ml/s, goutte en 3,4 s, 6,1 ml |
| Montée : moins de 5,5 g à 8 bar, pic sous 1,8 g/s | 4,1 g, 1,35 g/s |
| Plateau : au-dessus de 6,8 bar·s/g, pompe sous 69 % | 8,3 bar·s/g, 67 % |
| Depuis 8 bar : plus de 13,3 s, moins de 1,28 g/s | 16,0 s, 1,07 g/s ; arrêt au poids, pas au temps |
| Thermique : noter commande, SSR et NTC à +20 s | ci-dessus ; 86,19 °C à +20 s |
| Capture prolongée à 40–60 s après l'arrêt | **non** : 19,9 s |

**Lecture.**

- *Énergie, mesuré.* La tasse froide ne vient pas d'un manque d'énergie :
  le SSR a fourni plus par millilitre que les deux infusions précédentes.
  Ce qui change, c'est le moment : à débit lent, la dette se rembourse
  lentement, la commande reste à 0 % 15,4 s au lieu de 11,5 à 12,4 s, et
  l'appoint ne reprend que 4,9 s avant l'arrêt. Avec ≈ 17,6 s de délai
  chauffe → sonde, il arrive après l'arrêt ; la NTC baisse encore 7 s après.
- *Perte thermique proportionnelle à la durée, estimé.* Une fuite de
  chaleur expliquerait mal l'écart : 4 s d'infusion de plus pour ≈ 0,8 °C
  de moins en tasse qu'au 6 octobre demanderait ≈ 300 W de pertes en plus
  (1,47 kJ/K), un quart de la résistance.
- *Écart au modèle, en simulation.* Rejouée avec la commande réelle, la
  moyenne en tasse vaut 89,85 °C (mesure −2,14 °C), le minimum 88,93 °C
  (mesure −5,5 °C), le pic 90,55 °C (mesure +1,2 °C). La NTC réelle baisse
  bien plus que le modèle. Sur les infusions avec remboursement, l'écart
  suit la durée du 0 % :

  | Infusion | 0 % pendant | Tasse sous 0 % | Mesure − modèle (tasse) |
  | --- | ---: | ---: | ---: |
  | 06/10 7 h 19 | 11,5 s | 14,6 g | −0,68 °C |
  | 05/10 7 h 26 | 12,4 s | 14,7 g | −0,99 °C |
  | 08/10 8 h 43 | 15,4 s | 15,8 g | −2,14 °C |
  | 04/10 13 h 24 (coupure de fin en plus) | 21,8 s | 19,3 g | −1,99 °C |

  Avant le remboursement, résistance en marche pendant l'écoulement,
  l'écart était positif (+1,9 °C à 9 h 43 le 30 septembre). Hypothèse non
  testée : sans chauffe, plus de brassage par convection ; l'eau froide
  admise stratifie autour de la NTC, qui voit une capacité locale plus
  petite que les 1,47 kJ/K du modèle. Ce serait le « facteur manquant » de
  [chauffe-infusion.md](chauffe-infusion.md#simulation).
- *Eau du réservoir.* Non mesurée ; les trois dernières infusions sont du
  matin, rien ne la sépare de la durée.

**Décision.** David grossit un peu la mouture pour la prochaine infusion.
Réglages inchangés (`configs/261005-075907.json`). La loi de chauffe reste
telle quelle jusqu'au panier SCACE, attendu dans deux infusions : il dira
si le creux de la NTC est aussi celui de l'eau au groupe avant de toucher
au remboursement (plafond ou plancher de commande).

**Attendus pour l'infusion suivante** (même configuration, mouture entre
celles du 6 et du 8 octobre) :

| Point | Attendu |
| --- | --- |
| Remplissage | fin à 0,8 bar, 19 à 22 ml, ≈ 6 s |
| Pré-infusion à 50 % | goutte entre 2,1 et 3,4 s, 4 à 6 ml |
| Plateau | résistance entre 6,3 et 8,3 bar·s/g, pompe entre 67 et 69 % |
| Depuis 8 bar | entre 11,8 et 16,0 s, entre 1,07 et 1,35 g/s |
| Commande à 0 % | entre 11,5 et 15,4 s ; plus court avec un débit plus fort |
| Moyenne en tasse | entre 87,7 et 88,5 °C si l'écart suit la durée du 0 % ; sous la consigne dans tous les cas |
| Modèle, commande réelle | écart entre −0,7 et −2,1 °C, pour situer le point dans le tableau ci-dessus |

### 8 octobre, 13 h 44 — `261008-134433`

**Contexte.** Firmware, loi de chauffe et réglages d'infusion inchangés
depuis le matin (même remplissage, pré-infusion, cible et arrêt que
`configs/261005-075907.json`). Mouture un peu grossie depuis 8 h 43. Pas de
SCACE dans la capture. Observations de David : la mouture reste trop fine,
mais moins que ce matin ; il change la finesse pas à pas, c'est plus un
chemin qu'un saut. L'arrêt s'est fait quand le filet commençait à blondir :
proche de ce qu'il attend. Le goût est bon.

**Hydraulique.**

| Phase | Début | Durée | Volume | Pression |
| --- | ---: | ---: | ---: | --- |
| Précharge | 0,01 s | 8,00 s | — | — |
| Remplissage | 8,01 s | 5,80 s | 20,3 ml (3,50 ml/s) | 0,37 → 0,83 bar |
| Pré-infusion | 13,81 s | 3,40 s | 6,7 ml (1,96 ml/s) | 0,83 → 1,18 bar |
| Infusion | 17,21 s | 18,90 s | 33,3 ml | 9,02 bar max |

- Pression au repos avant l'infusion : 0,30 bar piégés (0,44 bar le
  matin).
- Premier paquet au-dessus de 0,8 bar à 13,71 s (19,7 ml, 5,7 s après le
  début du remplissage), passage en pré-infusion à 13,81 s : 100 ms, contre
  200 ms le 6 et le 8 octobre au matin. Même écart inexpliqué que le
  5 octobre au regard des 150 ms de [firmware.md](firmware.md).
- Le firmware a vu la première goutte à 17,21 s et 27,0 ml, 0,6 s avant
  l'échéance, comme le matin ; le rapport la place aussi à 27,0 ml
  (≥ 0,3 g). Marge de remplissage : 6,7 ml (6,1 à 6,7 ml le matin).
- La pré-infusion a duré exactement comme le matin (3,40 s), mais a passé
  6,7 ml au lieu de 6,1 : 1,96 contre 1,79 ml/s.
- Montée de 4,0 s jusqu'à 8 bar (4,5 s le matin), avec 3,8 g en tasse
  (4,1 g le matin). Pompe à 100 % de 19,8 à 20,9 s. Débit en tasse au plus
  de 1,35 g/s vers 20,7 s, sous ≈ 6,2 bar.
- Depuis 8 bar : 15,0 s, 1,15 g/s en tasse, 1,39 ml/s en amont, 21,5 g à
  l'arrêt (au poids), 22,2 g final.
- Plateau (de 8 bar + 2 s à l'arrêt − 0,5 s) : 8,87 ± 0,07 bar, pompe à
  66 %, 1,18 g/s, soit **7,5 bar·s/g** : entre le 6 octobre (6,3, trop
  grossière) et le matin (8,3, trop fine), ≈ 10 % sous le matin. C'est la
  mesure de ce que vaut le pas de mouture fait à midi.
- Après l'arrêt, la pression piégée tombe à 6,98 bar puis remonte à
  9,38 bar en 8 s, comme le matin.

**Thermique.**

| Grandeur | Mesure |
| --- | ---: |
| NTC pondérée par la tasse | **88,80 °C** (−1,20 °C) |
| NTC pondérée par le volume | 89,93 °C |
| Pic avant l'infusion | 92,07 °C, à 13,41 s (fin du remplissage) |
| Minimum pendant l'écoulement | 87,65 °C, à l'arrêt de la pompe |
| Minimum total | 86,18 °C à 42,0 s, ≈ 5,8 s après l'arrêt (3,81 °C sous la NTC de départ, 89,99 °C) |
| 20 s après l'arrêt (fin de la capture) | 88,23 °C, en hausse |

| Phase | Commande | SSR |
| --- | ---: | ---: |
| Précharge | 8,54 kJ | 8,40 kJ |
| Remplissage | 5,19 kJ | 4,44 kJ |
| Pré-infusion | 2,52 kJ | 2,28 kJ |
| Infusion | 2,27 kJ | 2,28 kJ |
| Récupération | 3,69 kJ | 3,96 kJ |

La commande reste à 0 % de 17,31 à 31,31 s (**14,0 s**), puis suit le
débit à 34–46 % pendant les 4,8 dernières secondes. 15,6 des 21,5 g en
tasse arrivent pendant ce 0 %. De la précharge à l'arrêt : 18,5 kJ
commandés, 17,4 kJ fournis par le SSR, pour 60,3 ml admis, soit
0,289 kJ/ml fournis (0,298 le matin, 0,286 le 6 octobre).

**Attendus vérifiés** (entrée du 8 octobre, 8 h 43) :

| Attendu | Mesure |
| --- | --- |
| Remplissage : fin à 0,8 bar, 19 à 22 ml, ≈ 6 s | 20,3 ml, 5,8 s |
| Pré-infusion : goutte entre 2,1 et 3,4 s, 4 à 6 ml | goutte en 3,4 s ; **6,7 ml**, un peu au-dessus |
| Plateau : entre 6,3 et 8,3 bar·s/g, pompe entre 67 et 69 % | 7,5 bar·s/g ; pompe à **66 %**, un point sous la fourchette |
| Depuis 8 bar : entre 11,8 et 16,0 s, entre 1,07 et 1,35 g/s | 15,0 s, 1,15 g/s |
| Commande à 0 % : entre 11,5 et 15,4 s | 14,0 s |
| Moyenne en tasse : entre 87,7 et 88,5 °C, sous la consigne | **non** : 88,80 °C, 0,3 °C au-dessus de la fourchette ; sous la consigne |
| Modèle, commande réelle : écart entre −0,7 et −2,1 °C | −1,33 °C |

**Lecture.**

- *Mouture, mesuré.* Le pas de midi a fait baisser la résistance au plateau
  de 8,3 à 7,5 bar·s/g et la durée depuis 8 bar de 16,0 à 15,0 s. La
  pré-infusion, elle, ne le voit pas : même durée jusqu'à la goutte, un peu
  plus de volume. Si le jugement de David tient (encore trop fine, goût
  bon), la cible est entre 6,3 et 7,5 bar·s/g, soit au plus un pas de plus
  si un pas vaut toujours ≈ 0,8 bar·s/g (estimé sur ce seul pas).
- *Tasse plus chaude que prévu, mesuré et en simulation.* Rejouée avec la
  commande réelle, la moyenne en tasse vaut 90,13 °C (mesure −1,33 °C), le
  minimum 89,11 °C (mesure −2,9 °C), le pic 90,97 °C (mesure +1,1 °C). Le
  point se range dans le tableau du matin, entre le 5 octobre et le matin :

  | Infusion | 0 % pendant | Tasse sous 0 % | Mesure − modèle (tasse) |
  | --- | ---: | ---: | ---: |
  | 06/10 7 h 19 | 11,5 s | 14,6 g | −0,68 °C |
  | 05/10 7 h 26 | 12,4 s | 14,7 g | −0,99 °C |
  | 08/10 13 h 44 | 14,0 s | 15,6 g | −1,33 °C |
  | 08/10 8 h 43 | 15,4 s | 15,8 g | −2,14 °C |

  L'écart suit toujours la durée du 0 %. Interpolé entre 12,4 et 15,4 s,
  il vaudrait ≈ −1,6 °C à 14,0 s : la mesure est ≈ 0,3 °C plus chaude, ce
  qui est aussi l'écart à la fourchette attendue. Deux causes possibles,
  non séparées : l'eau du réservoir, plus chaude à 13 h 44 qu'au matin
  (première infusion de l'après-midi depuis le 4 octobre), ou la dispersion
  ordinaire d'une relation tirée de trois points. La NTC de départ, 0,2 °C
  au-dessus du matin, joue dans le même sens mais le modèle la connaît déjà.
- *Pic avant l'infusion, mesuré.* 92,07 °C contre 91,71 °C le matin, pour
  une commande identique en précharge ; départ 0,2 °C plus haut et
  remplissage 0,5 s plus court.
- *Minimum total, mesuré.* −3,81 °C sous le départ, contre −6,38 °C le matin
  et −3,92 °C le 6 octobre. L'appoint reprend aussi ≈ 5 s avant l'arrêt
  dans les deux infusions du jour ; ce qui change, c'est 1,4 s de 0 % en
  moins et une infusion plus courte de 1,5 s. Que cela suffise à 2,6 °C
  d'écart sur le minimum n'est pas vérifié : le modèle ne reproduit aucun
  des deux creux.

**Décision.** David grossit la mouture d'un pas de plus. Réglages
inchangés (`configs/261005-075907.json`). La mouture est la seule
variable entre cette infusion et la suivante.

**Attendus pour l'infusion suivante** (un pas plus gros, si un pas vaut
≈ 0,8 bar·s/g comme à midi ; estimé sur ce seul pas) :

| Point | Attendu |
| --- | --- |
| Remplissage | fin à 0,8 bar, 19 à 22 ml, ≈ 6 s |
| Pré-infusion à 50 % | goutte en 2,1 à 3,4 s, 4 à 7 ml |
| Plateau | 6,4 à 7,0 bar·s/g, pompe à 68–70 % |
| Depuis 8 bar | 12,5 à 14,5 s, 1,2 à 1,35 g/s |
| Commande à 0 % | 12 à 13,5 s |
| Moyenne en tasse | 88,5 à 89,3 °C si l'écart suit le 0 % ; plus froide si l'infusion est du matin et que l'eau du réservoir compte |
| Modèle, commande réelle | écart de −0,9 à −1,4 °C |
| Filet à 22 g | moins blond qu'ici : à débit plus fort, la galette s'épuise plus tard |

Une infusion du matin et une de l'après-midi à mouture égale sépareraient
l'eau du réservoir de la durée du 0 % ; mesurer la température du réservoir
au moment de l'infusion suffirait aussi.

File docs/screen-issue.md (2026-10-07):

# Instabilité de synchronisation de l’écran

## Écritures flash et cache PSRAM (2026-10-07)

### Symptômes

- L'image glisse à chaque flash : c'est le cas le plus facile à reproduire.
- Un décalage fixe peut survivre à un reboot logiciel : après un flash,
  démarrage en mode Wi-Fi, puis `/confirm`, l'écran est toujours décalé.
- L'écran perd sa synchronisation pendant l'activité réseau.

### Cause probable

En mode « bounce buffer + framebuffer PSRAM », la documentation ESP-IDF 6.1
(`rgb_lcd.rst`) est explicite : le LCD **ne peut pas fonctionner** tant que le
cache de la mémoire externe est désactivé, ce qui arrive pendant toute
écriture ou tout effacement de la flash principale (OTA, NVS). L'ISR qui
remplit les bounce buffers lit le framebuffer à travers ce cache. Bloquée,
elle laisse le DMA LCD sans données, et l'image glisse. La même documentation
recommande `CONFIG_SPIRAM_XIP_FROM_PSRAM` : le code et les données en lecture
seule s'exécutent alors depuis la PSRAM, et le cache externe reste actif
pendant les écritures flash.

Le firmware écran écrit en flash alors que le flux RGB tourne :

- OTA écran par HTTP (`esp_ota_write`) et dépôt OTA capteurs dans
  `ota_staging` (effacement de la partition entière, puis écritures) ;
- `/confirm` : `esp_ota_mark_app_valid_cancel_rollback()` réécrit `otadata` ;
- démarrage Wi-Fi : la calibration PHY peut être enregistrée en NVS
  (`CONFIG_ESP_PHY_CALIBRATION_AND_DATA_STORAGE=y`) ;
- réglages et identifiants Wi-Fi (NVS).

Le décalage qui « survit » au reboot n'en serait pas un : chaque démarrage
en mode Wi-Fi refait une écriture flash pendant que le flux RGB tourne, et
recrée donc le décalage. Cela expliquerait aussi qu'une reprise à 1 s ne
suffisait pas et qu'une reprise à 5 s, après l'init radio, aide. Cette
explication reste une hypothèse : aucun log ne relie encore une écriture
précise au décalage.

### Ce que les exemples Waveshare apportent

Le README des exemples ESP-IDF `08_lvgl_v8_demo` et `09_lvgl_v9_demo` annonce
la bibliothèque `ESP32_Display_Panel`. C'est une couche C++ d'Espressif qui
décrit des cartes connues (brochage, timings, CH422G, GT911,
rétroéclairage) et appelle en dessous le même `esp_lcd_new_rgb_panel()` que
nous. Le code des exemples ne l'utilise d'ailleurs pas : il passe par un
`waveshare_rgb_lcd_port.c` local sur `esp_lcd`. Elle n'apporte rien de plus
au niveau matériel :

- le reset de la dalle par EXIO3 (LCD_RST) existe déjà chez nous ;
- les timings Waveshare ne sont pas cohérents d'une source à l'autre :
  `ESP32_Display_Panel` utilise HSYNC `4/8/8` et VSYNC `4/8/8` ; les exemples
  IDF proposent, sous `#if`, `30/145/170` et `2/23/12` ou bien `4/8/8` et
  `4/8/8`. Les nôtres (`48/88/40`, `3/32/13`) sont validés sur ce panneau et
  ne changent pas.

La différence utile est dans le `sdkconfig.defaults` de l'exemple v9 :
`CONFIG_SPIRAM_XIP_FROM_PSRAM=y`, avec une PSRAM à 120 MHz, des caches
agrandis (instructions 32 Kio, données 64 Kio en lignes de 64 octets dans
l'exemple v8) et une flash en QIO.

### Essai 1 : XIP seul

`CONFIG_SPIRAM_XIP_FROM_PSRAM=y`, qui entraîne `SPIRAM_FETCH_INSTRUCTIONS` et
`SPIRAM_RODATA`. Caches, vitesse PSRAM (80 MHz), timings, bounce buffers,
PCLK et reprise à 5 s ne changent pas.

Coût attendu : l'image est copiée en PSRAM au démarrage (environ 1,7 Mo sur
8 Mo), et chaque défaut du cache d'instructions lit désormais la PSRAM. Ces
lectures partagent la bande passante avec l'ISR des bounce buffers,
c'est-à-dire la contention déjà corrigée en septembre. Si de nouveaux sauts
apparaissent sous charge (infusion, balance connectée), c'est l'essai 2 qui
les traite : caches agrandis, à condition que la SRAM interne le permette.
La PSRAM à 120 MHz, expérimentale et sensible à la température, ne vient
qu'en dernier recours.

Pour relever la marge SRAM, l'écran de diagnostic et l'écran du mode Wi-Fi
affichent en bas la SRAM interne libre et le plus gros bloc allouable.

Protocole :

1. Flasher `0.3.43`. Ce flash ne teste rien : c'est l'ancienne image, sans
   XIP, qui écrit la flash, et l'image glisse comme avant.
2. Plusieurs démarrages en mode Wi-Fi, chacun suivi de `/confirm` : aucun
   décalage, avant comme après la reprise de 5 s. `/confirm` est la première
   écriture flash faite par l'image XIP.
3. Flasher de nouveau l'écran (même image ou suivante), puis le module
   capteurs, en regardant la dalle : c'est maintenant l'image XIP qui écrit,
   l'image ne doit plus glisser.
4. Une infusion avec la balance connectée : aucun saut. Relever les deux
   valeurs SRAM sur l'écran de diagnostic, puis en mode Wi-Fi.

### Résultats (`0.3.43` et `0.3.44`)

**Glissement pendant les écritures flash : corrigé.** Le flash de `0.3.44`,
écrit par `0.3.43` avec XIP, n'a plus fait glisser l'image du tout.

**Marge SRAM interne** (plus gros bloc 31 K dans tous les cas) :

| Mode | Libre |
|---|---|
| Machine (BLE), balance connectée ou non | 88 à 91 K |
| Wi-Fi | 77 K |

Les caches agrandis (essai 2) ne seront essayés que si des sauts
réapparaissent pendant une infusion.

**Décalage fixe au démarrage : toujours présent, indépendant de XIP.**

- Il apparaît au hasard, environ un démarrage sur 5 à 10. Une séquence
  isolée (par exemple `/confirm` suivi d'un redémarrage décalé) ne permet
  donc aucune conclusion.
- Il est déjà visible sur la bannière « coffeeflow », avant toute pile
  radio : ni le Wi-Fi, ni BLE, ni la transition entre les deux n'en sont la
  cause.
- Au dernier essai, la reprise manuelle (`esp_lcd_rgb_panel_restart()`,
  case « firmware », page 3 des réglages) ne remettait pas l'image en place.
  Cela contredit la conclusion de `v0.2.33` ; à revérifier sur plusieurs
  occurrences.

Un état que le redémarrage du flux DMA ne corrige pas, et qui survit à un
reboot logiciel, désigne plutôt la dalle que l'ESP32.

**Ce que montre le schéma Waveshare** (connecteur 40 broches de la dalle,
PORT1) :

- `LCD_RST` (EXIO3) arrive sur la broche 35, marquée `NC`. Le « reset
  dalle » de `board::panel_power_on()` ne réinitialise vraisemblablement
  rien. La dalle est alimentée directement en 3V3 : seule une coupure
  d'alimentation la réinitialise.
- `DISP` (EXIO2, `kCh422gDisp`) commande la broche 31 `DISP` de la
  dalle (veille / marche) **et** l'entrée EN du convertisseur de
  rétroéclairage MP3302, avec un tirage de 10 kΩ au 3V3. Couper le
  rétroéclairage met donc aussi la dalle en veille.

Notre démarrage met `DISP` à 0, démarre le flux RGB, puis remet `DISP` à 1
après le premier rendu LVGL : la dalle sort de veille à un instant
quelconque de la trame. Waveshare, de son côté, passe toutes les sorties du
CH422G à 1 dès son initialisation : `DISP` est haut avant le démarrage du
flux et n'est plus jamais modifié. Hypothèse, non vérifiée faute de
datasheet de la dalle : la sortie de veille au milieu d'une trame fige
parfois une mauvaise phase dans le contrôleur de la dalle, et seule une
nouvelle sortie de veille ou une coupure d'alimentation la libère.

**Le décalage est toujours exactement le même, en X comme en Y.** Ce n'est
donc pas une phase aléatoire : la dalle bascule entre deux états
déterministes. Les contrôleurs de ces dalles RGB 40 broches acceptent
deux modes : DE, où la position de l'image suit le signal DE, et HV (SYNC),
où le premier pixel est pris à un nombre fixe de PCLK après HSYNC et de
lignes après VSYNC, quels que soient nos porches. Si la dalle démarre
parfois en mode HV, le décalage vaut :

- en X : `hsync_pulse_width + hsync_back_porch` (48 + 88 = 136) moins le
  back porch fixe de la dalle ;
- en Y : `vsync_pulse_width + vsync_back_porch` (3 + 32 = 35) moins son
  back porch vertical fixe.

Les valeurs fixes de la dalle sont inconnues sans datasheet. À titre
d'exemple, les valeurs courantes des dalles 800×480 de ce type (46 PCLK, 23
lignes) donneraient 90 px vers la droite et 12 lignes vers le bas : même
sens que l'observation (« environ 150 px à droite, légèrement plus bas »,
estimé au toucher).

Si l'hypothèse tient, le correctif ne dépend pas de la cause du basculement :
choisir les porches pour que la somme impulsion + back porch soit égale au
back porch fixe de la dalle, en X comme en Y. Les deux modes produisent
alors la même image. Il faut pour cela mesurer le décalage exact en pixels
dans l'état décalé.

**Essai `0.3.45` : `DISP` haut dès la première écriture CH422G.** Avant,
`select_can()` remettait `DISP` à 0 à chaque démarrage (veille de la dalle,
y compris après un reboot logiciel), et `DISP` ne remontait qu'après le
premier rendu LVGL, flux RGB déjà lancé. Désormais `DISP` est à 1 dès
`select_can()` et n'est plus jamais modifié, comme chez Waveshare. La
séquence LCD_RST/TP_RST de `panel_power_on()` est inchangée. Le
rétroéclairage s'allume donc dès le démarrage : l'écran est blanc jusqu'au
démarrage du flux RGB, puis la bannière s'affiche. C'est accepté si le
décalage disparaît ; le résultat se juge sur plusieurs jours.

Mesurer le décalage exact (mire affichée avant la bannière, maintenue
jusqu'au premier toucher) ne sert que si cet essai échoue : elle permettrait
de confirmer le mode HV et de caler les porches pour que les deux modes
donnent la même image.

**Combien de démarrages pour conclure.** Avec un défaut tous les 5 à 10
démarrages (10 à 20 %), une série sans aucun décalage doit compter au moins
30 démarrages. Si le défaut est toujours là à 10 %, 30 démarrages propres
ont 4 % de chances d'arriver par hasard ; à 20 %, 0,1 %. Avec 20
démarrages, ces chances montent à 12 % et 1 %.

## Nouvel essai (2026-09-15)

Le décalage fixe reste observable sur certains démarrages malgré la reprise
unique ajoutée en `v0.2.33`. Un essai à PCLK 12 MHz a placé la dalle dans une
boucle de mires blanc/rouge/vert/bleu/noir ; PCLK reste donc à 16 MHz. La reprise
automatique est repoussée de 1 à 5 secondes afin qu'elle arrive après le
démarrage normal de la radio. La case « firmware » de la troisième page des
réglages permet aussi de demander manuellement une reprise au prochain VSYNC.

## Résultat final (2026-09-10, `v0.2.33`)

Le correctif `v0.2.20` a supprimé les sauts et décalages variables observés
pendant les rafraîchissements, mais la conclusion « écran parfaitement stable »
était trop forte. Un décalage fixe persistait : tout le contenu apparaissait
environ 150 pixels trop à droite et légèrement trop bas. Pour cliquer sur un
bouton affiché, il fallait toucher environ 150 pixels à sa gauche et un peu
plus haut.

Le test `v0.2.33` confirme que le GT911 renvoyait les coordonnées LVGL
correctes et que seule la trame RGB visible était décalée. Une reprise unique
du panneau avec `esp_lcd_rgb_panel_restart()`, une seconde après le premier
rendu LVGL, remet l'image en place. La cause est donc le démarrage
désynchronisé du flux RGB/DMA, pas les coordonnées tactiles ni un offset LVGL.

Suffisant, flashé et observé : LCD initialisé depuis le cœur 1 (ISR DMA
avec LVGL), pont TWAI/UART et validation OTA sur le cœur 0.

Ne pas appeler `lv_label_set_text()` si le texte est inchangé : bonne
pratique posée dans `service_screen.cpp` (`set_label_if_changed()`),
documentée dans `firmware/screen/AGENTS.md`.

PCLK resté à 16 MHz, CPU resté à 160 MHz. Les images 2 (240 MHz) et 3
(PCLK 14 puis 12 MHz) n’ont pas été nécessaires. `CONFIG_LCD_RGB_RESTART_IN_VSYNC`
reste désactivé.

## Diagnostic des sauts variables (confirmé)

Ce n’était ni un mauvais timing HSYNC/VSYNC, ni un manque global de CPU pour
traiter le CAN.

Le symptôme correspondait à une sous-alimentation ponctuelle du DMA LCD :

- image décalée horizontalement : le LCD continue d’avancer pendant que le DMA
  attend des données ;
- saut occasionnel : ESP-IDF détecte les bounce buffers manqués et
  resynchronise le DMA au VSYNC suivant.

La documentation ESP-IDF 6.1 décrit explicitement ce cas : Core 1 écrit le
framebuffer PSRAM pendant que l’ISR LCD sur Core 0 copie ce même framebuffer
vers les bounce buffers, ce qui peut provoquer un « screen shift ».

C’était précisément la configuration fautive :

- `app_main()` tourne sur Core 0 et appelait `service_screen::init()` :
  l’interruption LCD était donc installée sur Core 0 ;
- LVGL était épinglé sur Core 1 ;
- LVGL écrivait dans le framebuffer PSRAM pendant que Core 0 le lisait ;
- l’écran de service réécrivait six labels toutes les 200 ms, même lorsque
  leur texte était inchangé.

`screen-lcd-test` n’était pas une charge équivalente : il ne modifie qu’un
minuscule compteur. Il prouve les timings et le panneau, mais pas la marge de
bande passante du vrai écran.

## Correctif appliqué

### 1. LCD et LVGL sur le cœur 1 — fait

`service_screen::init()` lance une tâche temporaire épinglée sur le cœur 1,
qui appelle `esp_lcd_new_rgb_panel()`. L’interruption LCD est donc attachée
au même cœur que LVGL : elle préempte les écritures framebuffer au lieu que
les deux cœurs accèdent simultanément à la PSRAM.

TWAI/UART restent installés depuis `app_main` (cœur 0). `can2ser`, `ser2can`
et `ota_valid` sont épinglés sur le cœur 0. Répartition en vigueur :

- Core 0 : TWAI, UART, pont, plus tard Wi-Fi/BLE ;
- Core 1 : LCD, LVGL, contrôle machine.

### 2. Ne redessiner que lorsqu’une valeur change — fait

`set_label_if_changed()` compare à `lv_label_get_text()` et n’appelle
`lv_label_set_text()` que si la chaîne diffère. `tick_presence()` continue
de tourner toutes les 200 ms, indépendamment du dessin. La construction
initiale des labels (`build_ui`) écrit directement : le widget est neuf.

### 3. CPU à 240 MHz — non nécessaire

Le remplissage des bounce buffers est un `memcpy()` dans l’ISR ; 240 MHz
donnerait 50 % de marge de plus. Inutile une fois 1 et 2 en place.

### 4. PCLK à 12 ou 14 MHz — non nécessaire

Avec les porches actuels : 16 MHz ≈ 31 Hz, 14 MHz ≈ 27 Hz, 12 MHz ≈ 23 Hz.
16 MHz tient, une fois la contention PSRAM/ISR levée.

### 5. `CONFIG_LCD_RGB_RESTART_IN_VSYNC` désactivé — conservé

En ESP-IDF 6.1, le driver détecte déjà les EOF manqués et redémarre uniquement
en cas de sous-alimentation. Cette option force le redémarrage à chaque VSYNC,
ce qui avait aggravé les sauts. Ne pas la réactiver.

Un downgrade vers ESP-IDF 5.x n'est pas recommandé : le firmware isolé était
déjà stable sous 6.1, et le correctif est architectural (affinité des cœurs),
pas une incompatibilité d'IDF.

## Décalage fixe — diagnostic confirmé et correctif

Les timings en vigueur sont ceux du sketch Waveshare validé sur ce panneau :
HSYNC `48/88/40`, VSYNC `3/32/13`, PCLK 16 MHz sur front descendant. Le
framebuffer 800×480 RGB565 est en PSRAM ; le driver `esp_lcd` utilise deux
bounce buffers DMA internes de 40 lignes et `esp_lvgl_port` est en `bb_mode`.

Le premier essai ciblé utilisait un timer LVGL une seconde après la construction
de l'UI. Le nouvel essai porte ce délai à cinq secondes. Le driver exécute la
reprise au VSYNC suivant et le moniteur reçoit `LCD_INIT_STEP=8`. Une demande
manuelle depuis les réglages émet `LCD_INIT_STEP=9`.

Ce restart unique est différent de `CONFIG_LCD_RGB_RESTART_IN_VSYNC`. Cette
option reste désactivée : redémarrer à chaque trame avait aggravé les sauts.
Les timings, les deux bounce buffers de 40 lignes et la configuration du GT911
ne changent pas. La bordure magenta ajoutée pour le
diagnostic a été retirée sans modifier le correctif.

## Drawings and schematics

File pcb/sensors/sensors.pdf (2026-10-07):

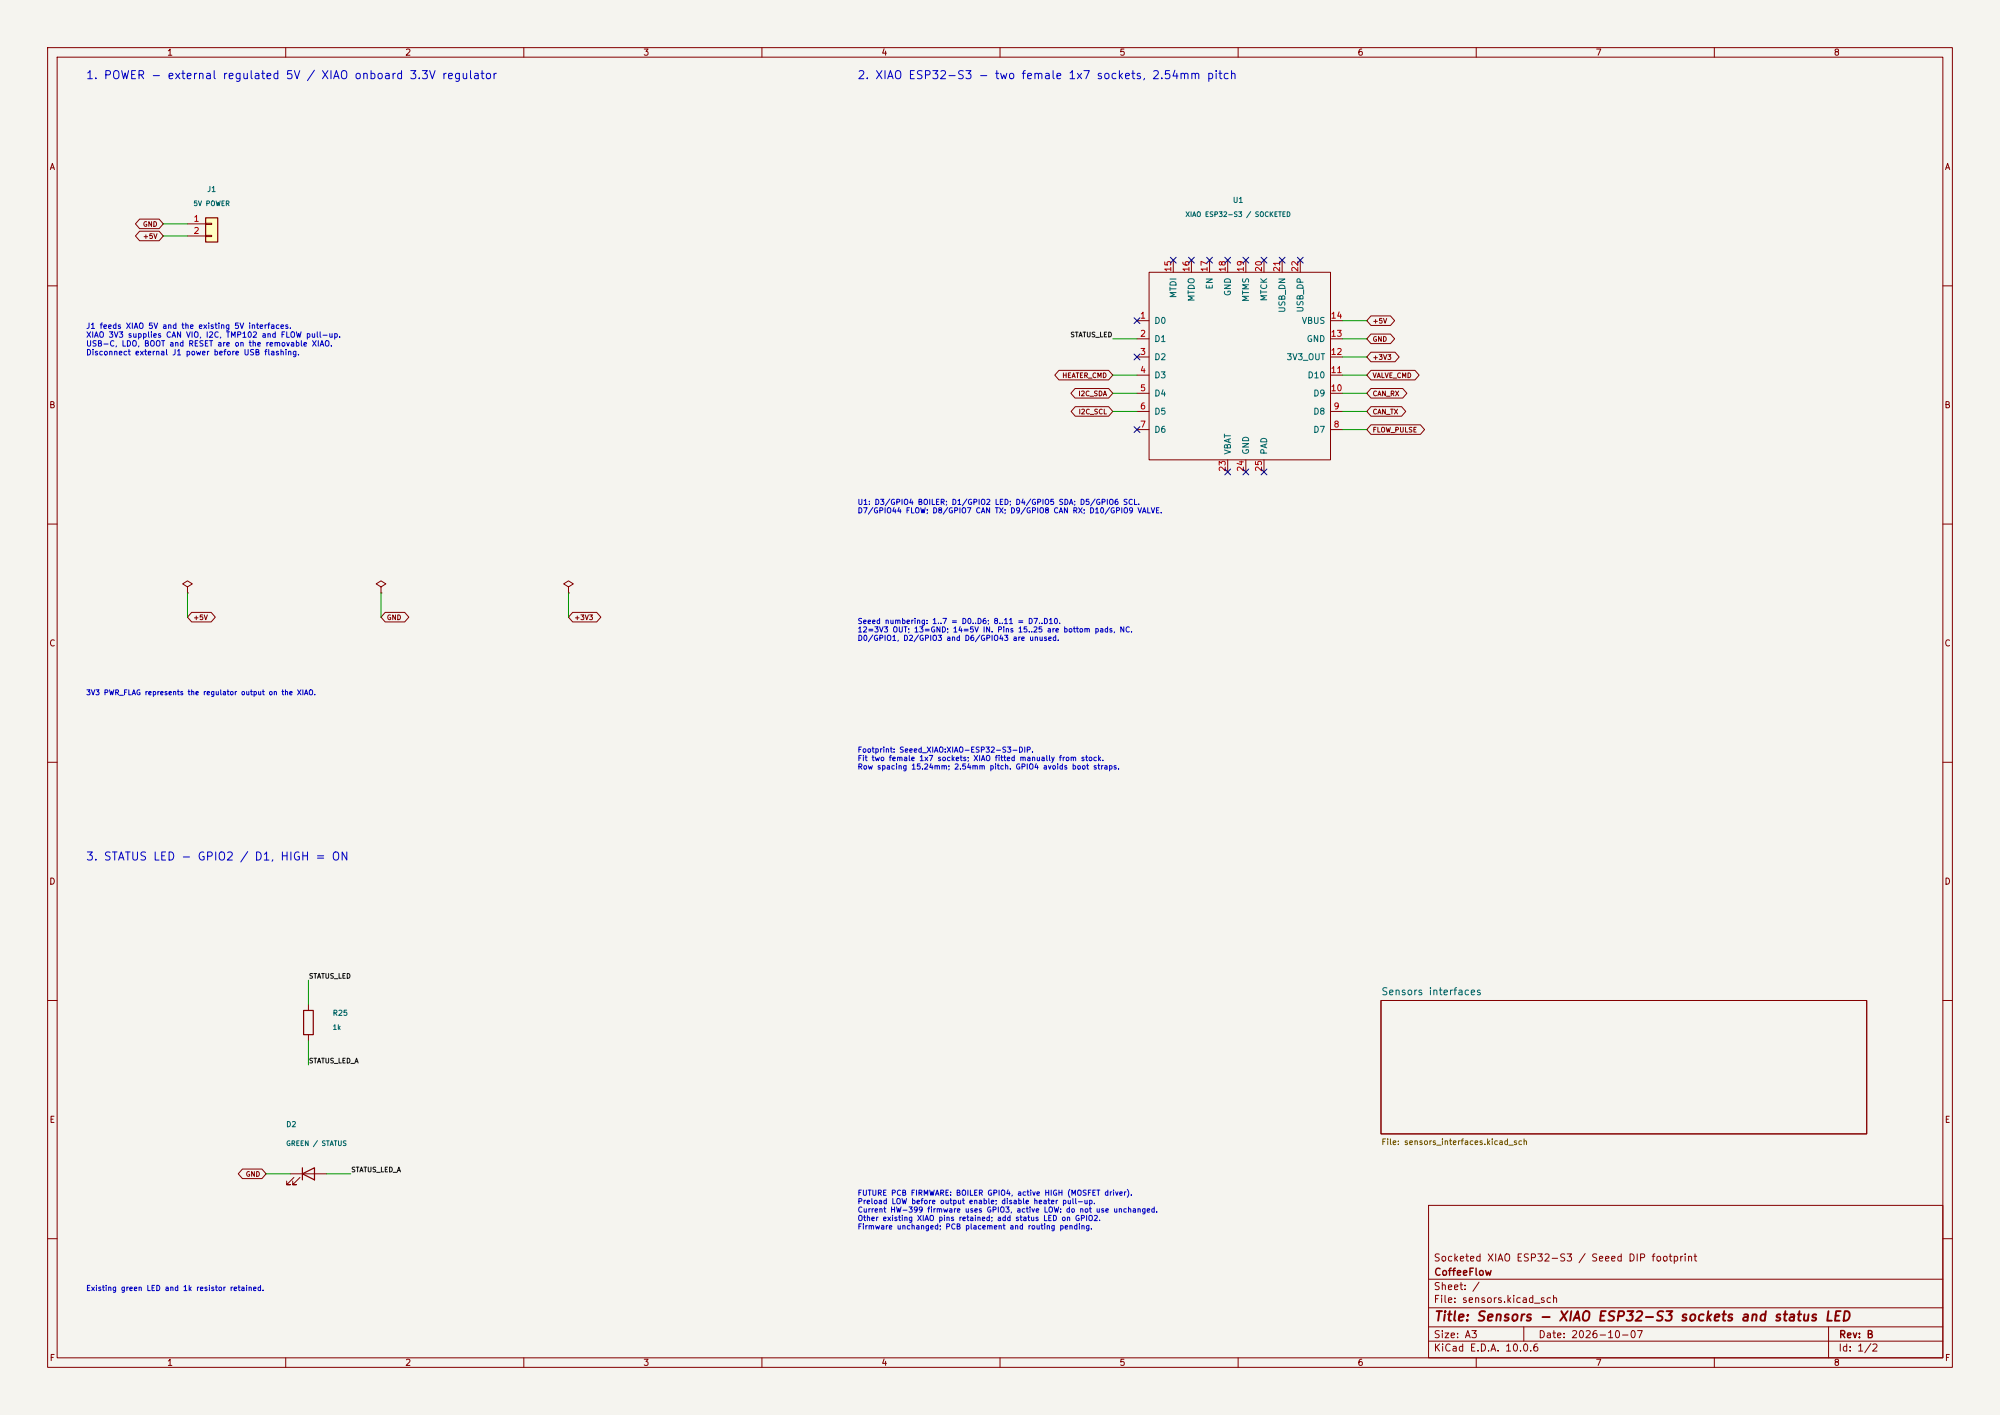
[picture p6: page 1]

1. POWER - external regulated 5V / XIAO onboard 3.3V regulator

2. XIAO ESP32-S3 - two female 1x7 sockets, 2.54mm pitch

J1 feeds XIAO 5V and the existing 5V interfaces. XIAO 3V3 supplies CAN VIO, I2C, TMP102 and FLOW pull-up. USB-C, LDO, BOOT and RESET are on the removable XIAO. Disconnect external J1 power before USB flashing.

Existing green LED and 1k resistor retained. 3. STATUS LED - GPIO2 / D1, HIGH = ON

FUTURE PCB FIRMWARE: BOILER GPIO4, active HIGH (MOSFET driver). Preload LOW before output enable; disable heater pull-up. Current HW-399 firmware uses GPIO3, active LOW: do not use unchanged. Other existing XIAO pins retained; add status LED on GPIO2. Firmware unchanged; PCB placement and routing pending.

Socketed XIAO ESP32-S3 / Seeed DIP footprint
CoffeeFlow
Sheet: /
File: sensors.kicad_sch
Title: Sensors - XIAO ESP32-S3 sockets and status LED

Size: A3 | Rev: B | F Date: 2026-10-07
KiCad E.D.A. 10.0.6 | Id: 1/2

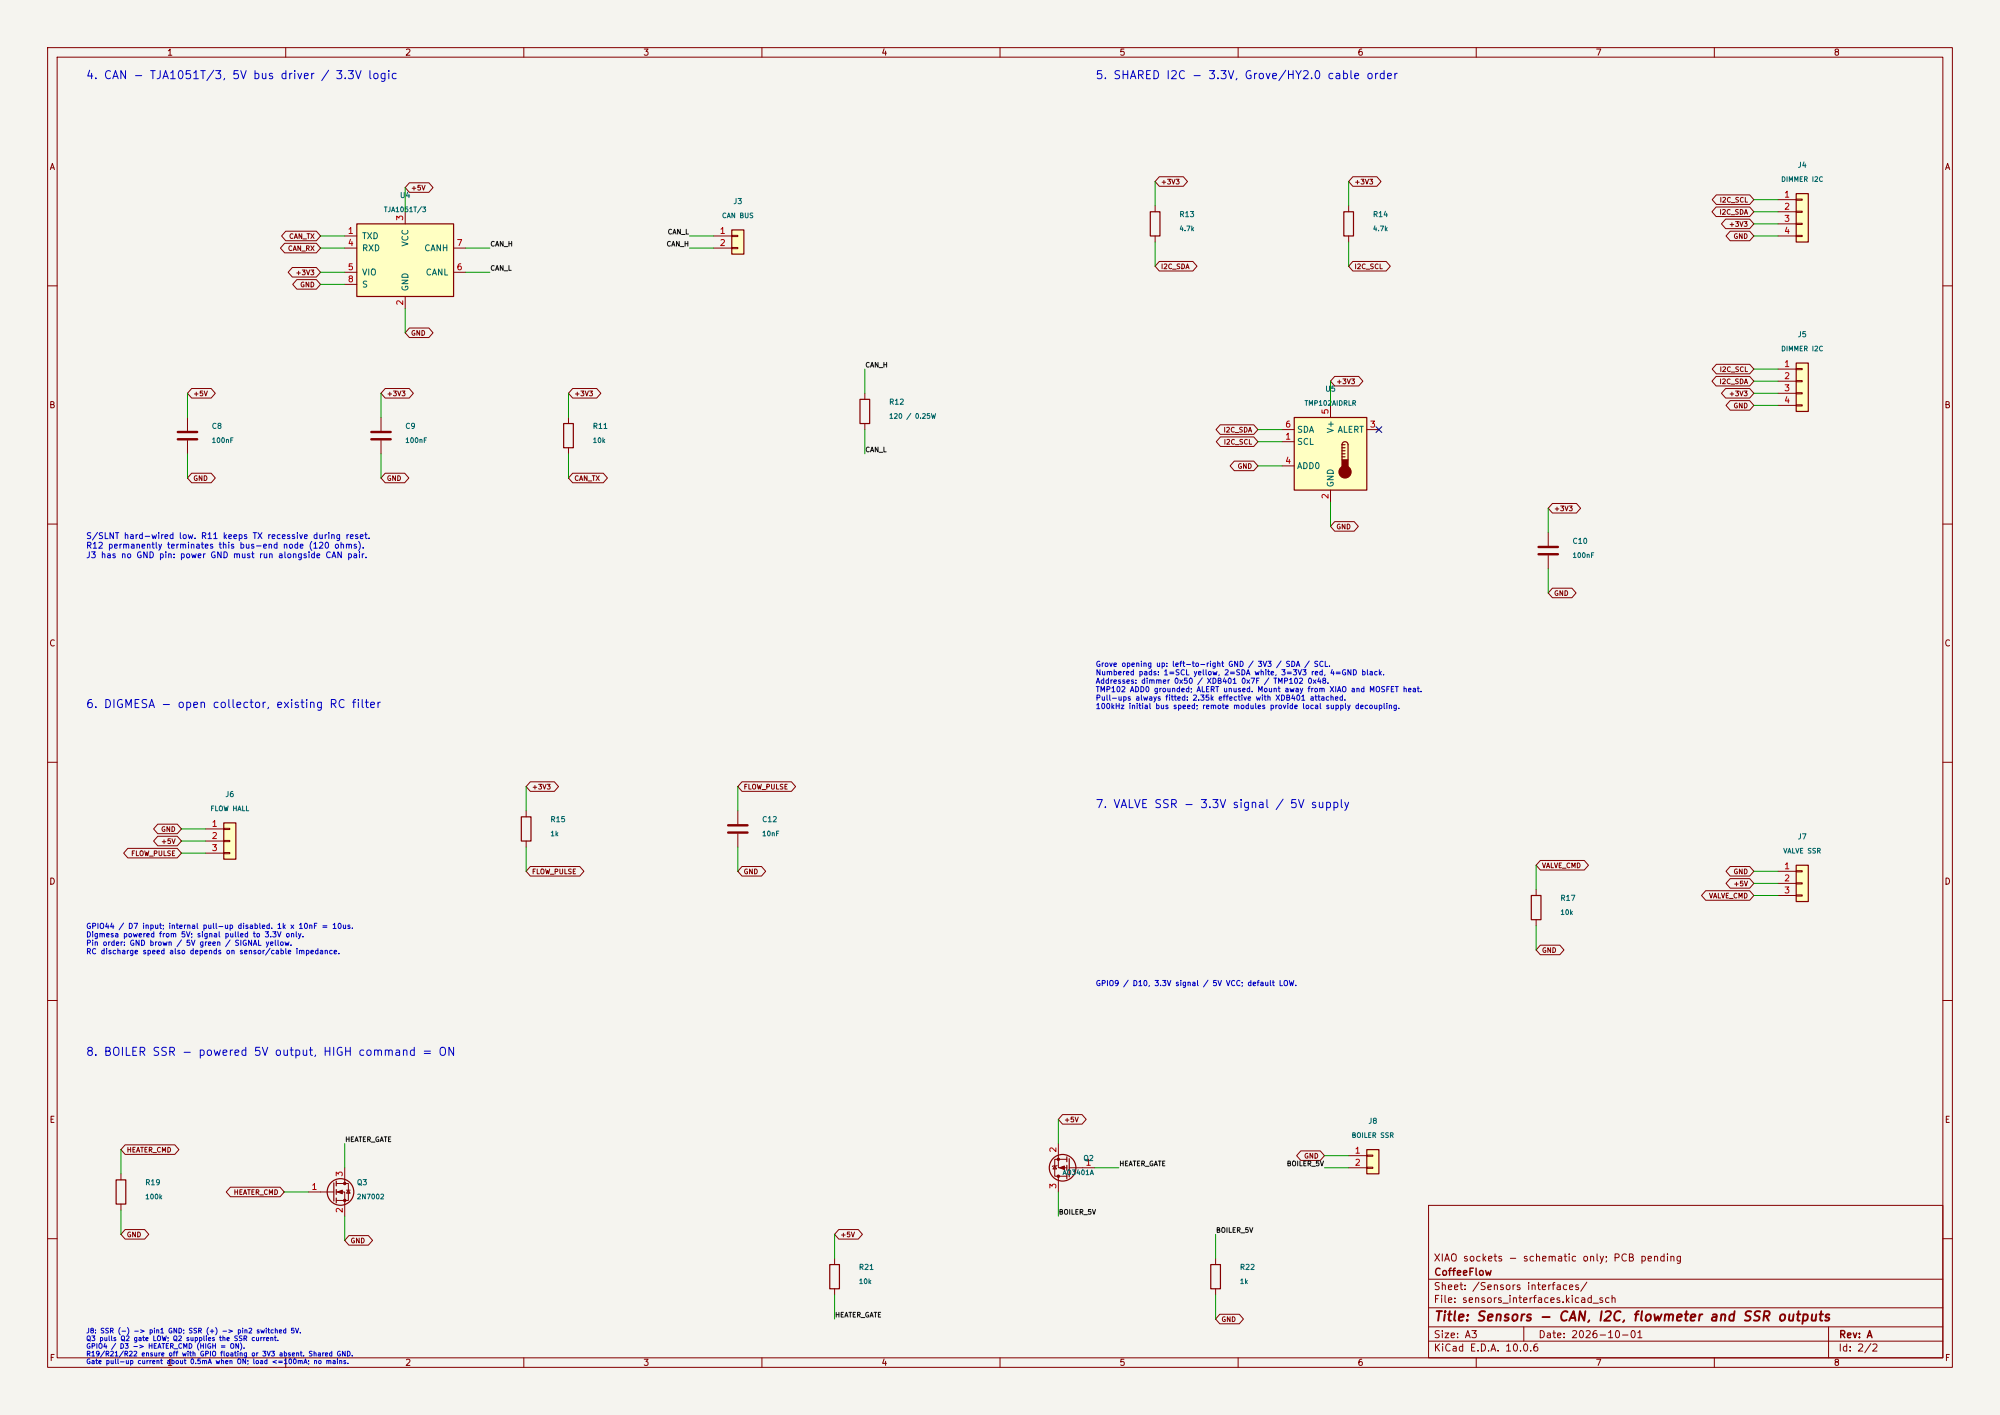
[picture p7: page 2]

S/SLNT hard-wired low. R11 keeps TX recessive during reset. R12 permanently terminates this bus-end node (120 ohms). J3 has no GND pin: power GND must run alongside CAN pair.

GPIO9 / D10, 3.3V signal / 5V VCC; default LOW. Grove opening up: left-to-right GND / 3V3 / SDA / SCL. Numbered pads: 1=SCL yellow, 2=SDA white, 3=3V3 red, 4=GND black. Addresses: dimmer 0x50 / XDB401 0x7F / TMP102 0x48. TMP102 ADD0 grounded; ALERT unused. Mount away from XIAO and MOSFET heat. Pull-ups always fitted: 2.35k effective with XDB401 attached. 100kHz initial bus speed; remote modules provide local supply decoupling.

6. DIGMESA - open collector, existing RC filter
GND

7. VALVE SSR - 3.3V signal / 5V supply

GPIO44 / D7 input; internal pull-up disabled. 1k x 10nF = 10us. Digmesa powered from 5V; signal pulled to 3.3V only. Pin order: GND brown / 5V green / SIGNAL yellow. RC discharge speed also depends on sensor/cable impedance.

J8: SSR (-) -> pin1 GND; SSR (+) -> pin2 switched 5V. Q3 pulls Q2 gate LOW; Q2 supplies the SSR current. GPIO4 / D3 -> HEATER_CMD (HIGH = ON). R19/R21/R22 ensure off with GPIO floating or 3V3 absent. Shared GND. Gate pull-up current about 0.5mA when ON; load <=100mA; no mains. 8. BOILER SSR - powered 5V output, HIGH command = ON

XIAO sockets - schematic only; PCB pending
CoffeeFlow
Sheet: /Sensors interfaces/
File: sensors_interfaces.kicad_sch
Title: Sensors - CAN, I2C, flowmeter and SSR outputs

Size: A3 | Rev: A | F Date: 2026-10-01
KiCad E.D.A. 10.0.6 | Id: 2/2

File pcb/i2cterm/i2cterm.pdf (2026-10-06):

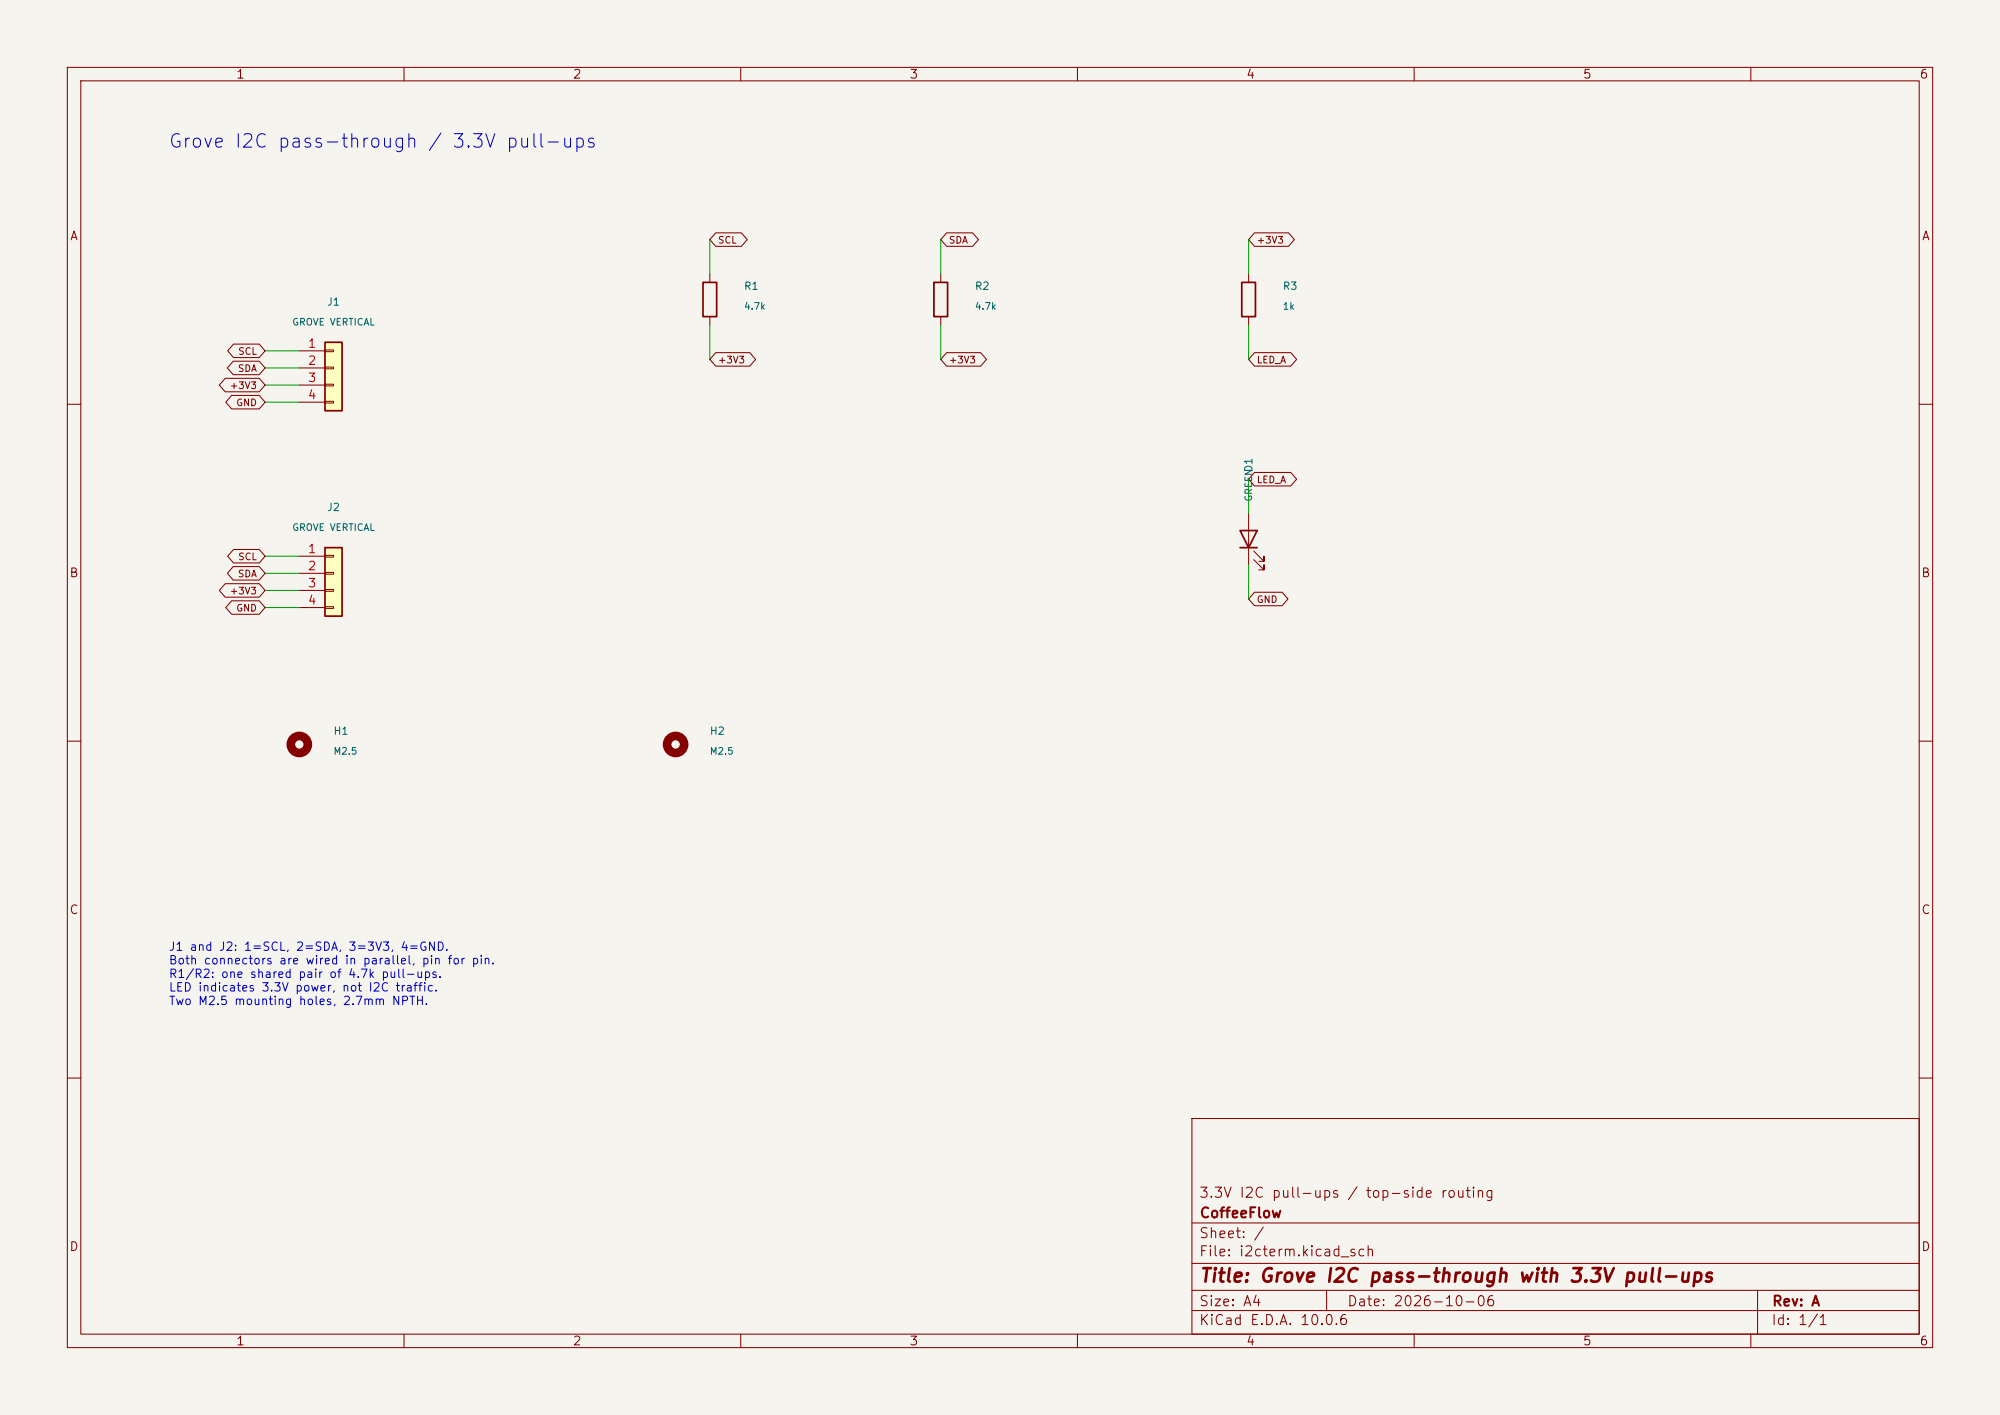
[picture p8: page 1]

R1/R2: one shared pair of 4.7k pull-ups. LED indicates 3.3V power, not I2C traffic. Two M2.5 mounting holes, 2.7mm NPTH. Grove I2C pass-through / 3.3V pull-ups

LED_A J1 and J2: 1=SCL, 2=SDA, 3=3V3, 4=GND. Both connectors are wired in parallel, pin for pin.

3.3V I2C pull-ups / top-side routing
CoffeeFlow
Sheet: /
File: i2cterm.kicad_sch
Title: Grove I2C pass-through with 3.3V pull-ups

Size: A4 | Rev: A
KiCad E.D.A. 10.0.6 | Id: 1/1

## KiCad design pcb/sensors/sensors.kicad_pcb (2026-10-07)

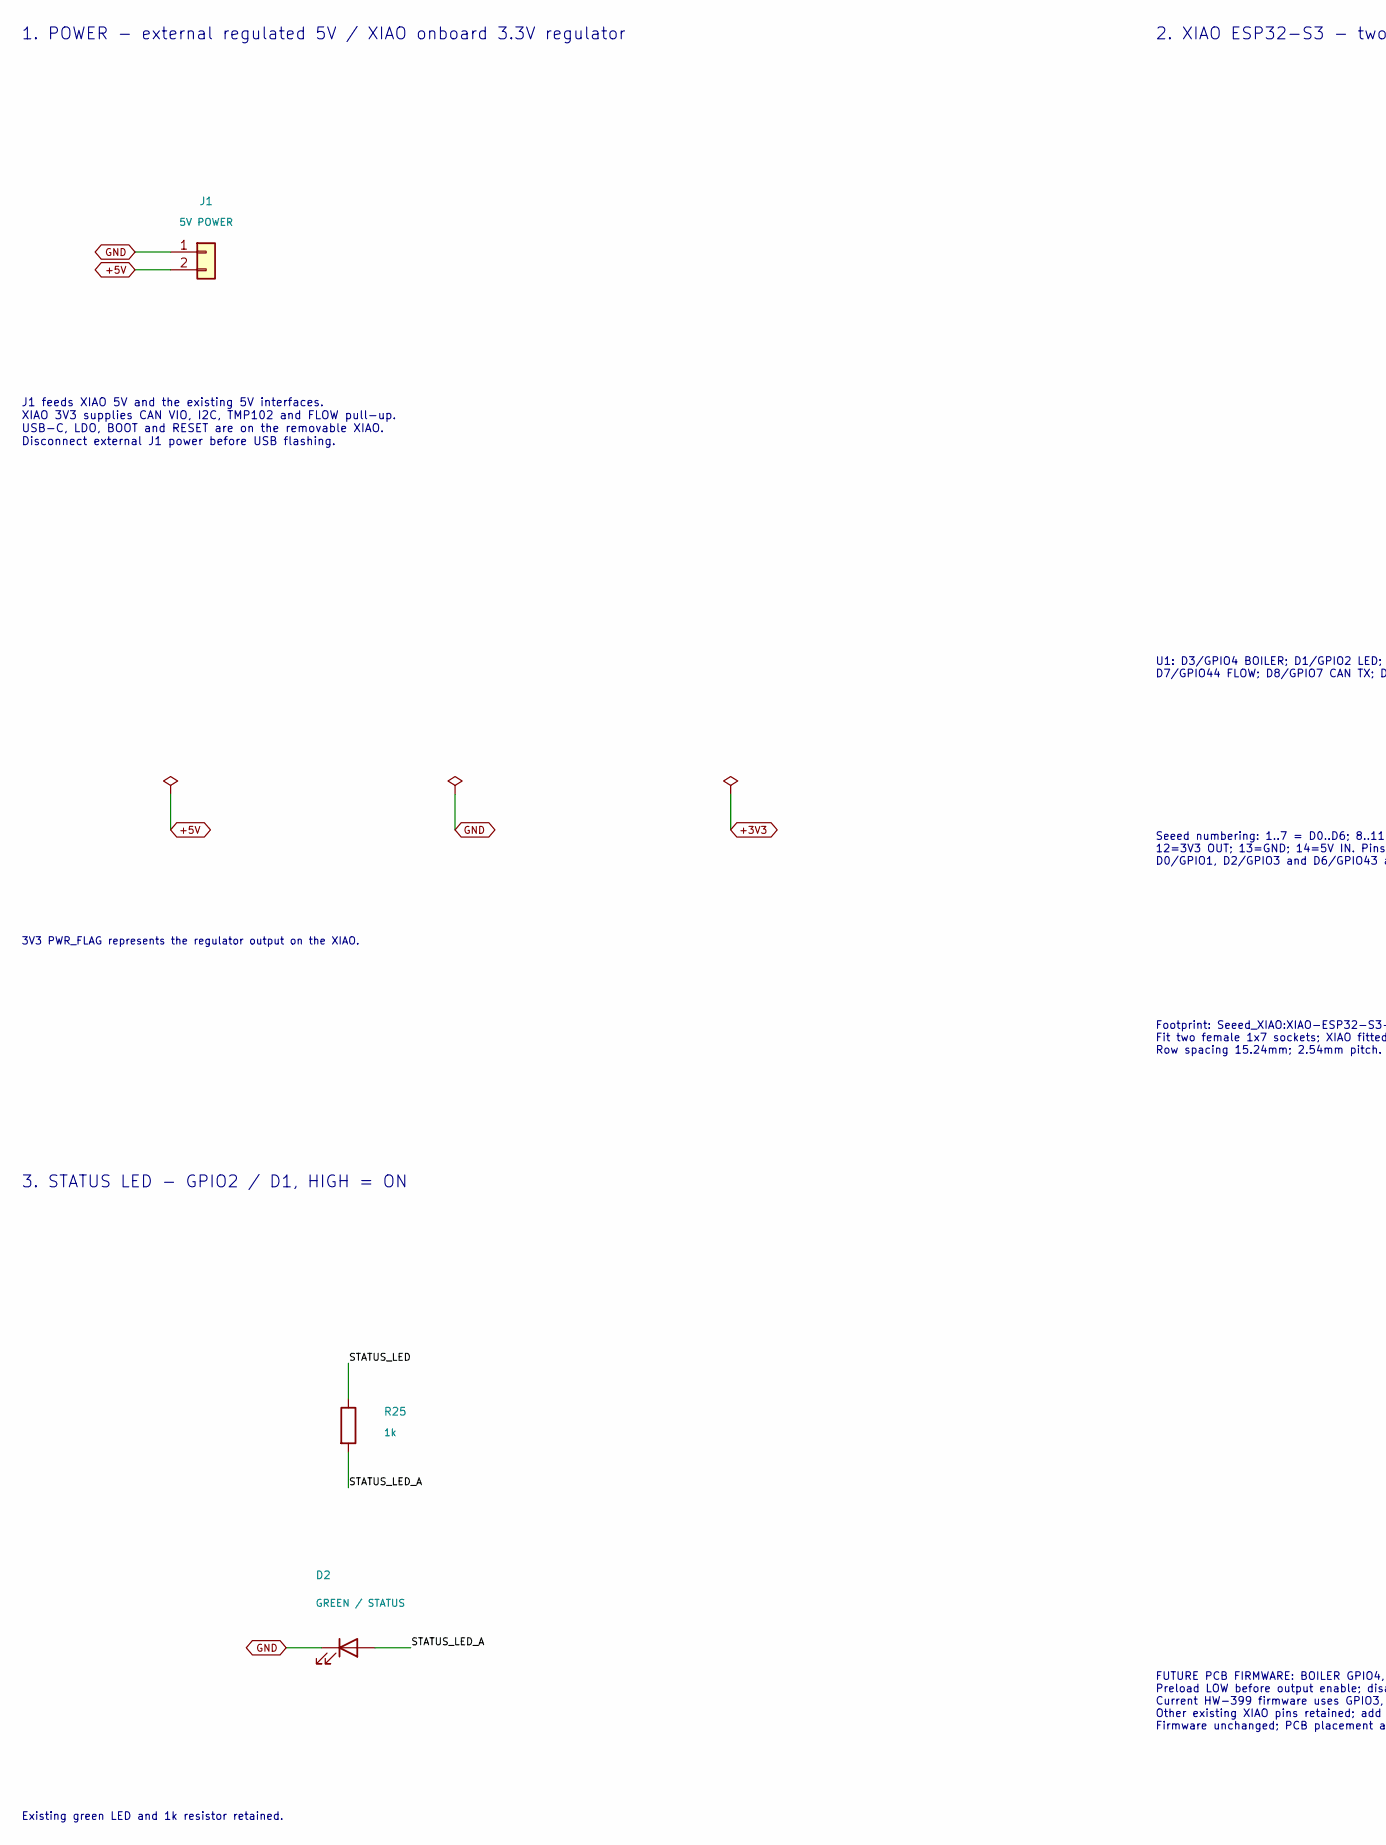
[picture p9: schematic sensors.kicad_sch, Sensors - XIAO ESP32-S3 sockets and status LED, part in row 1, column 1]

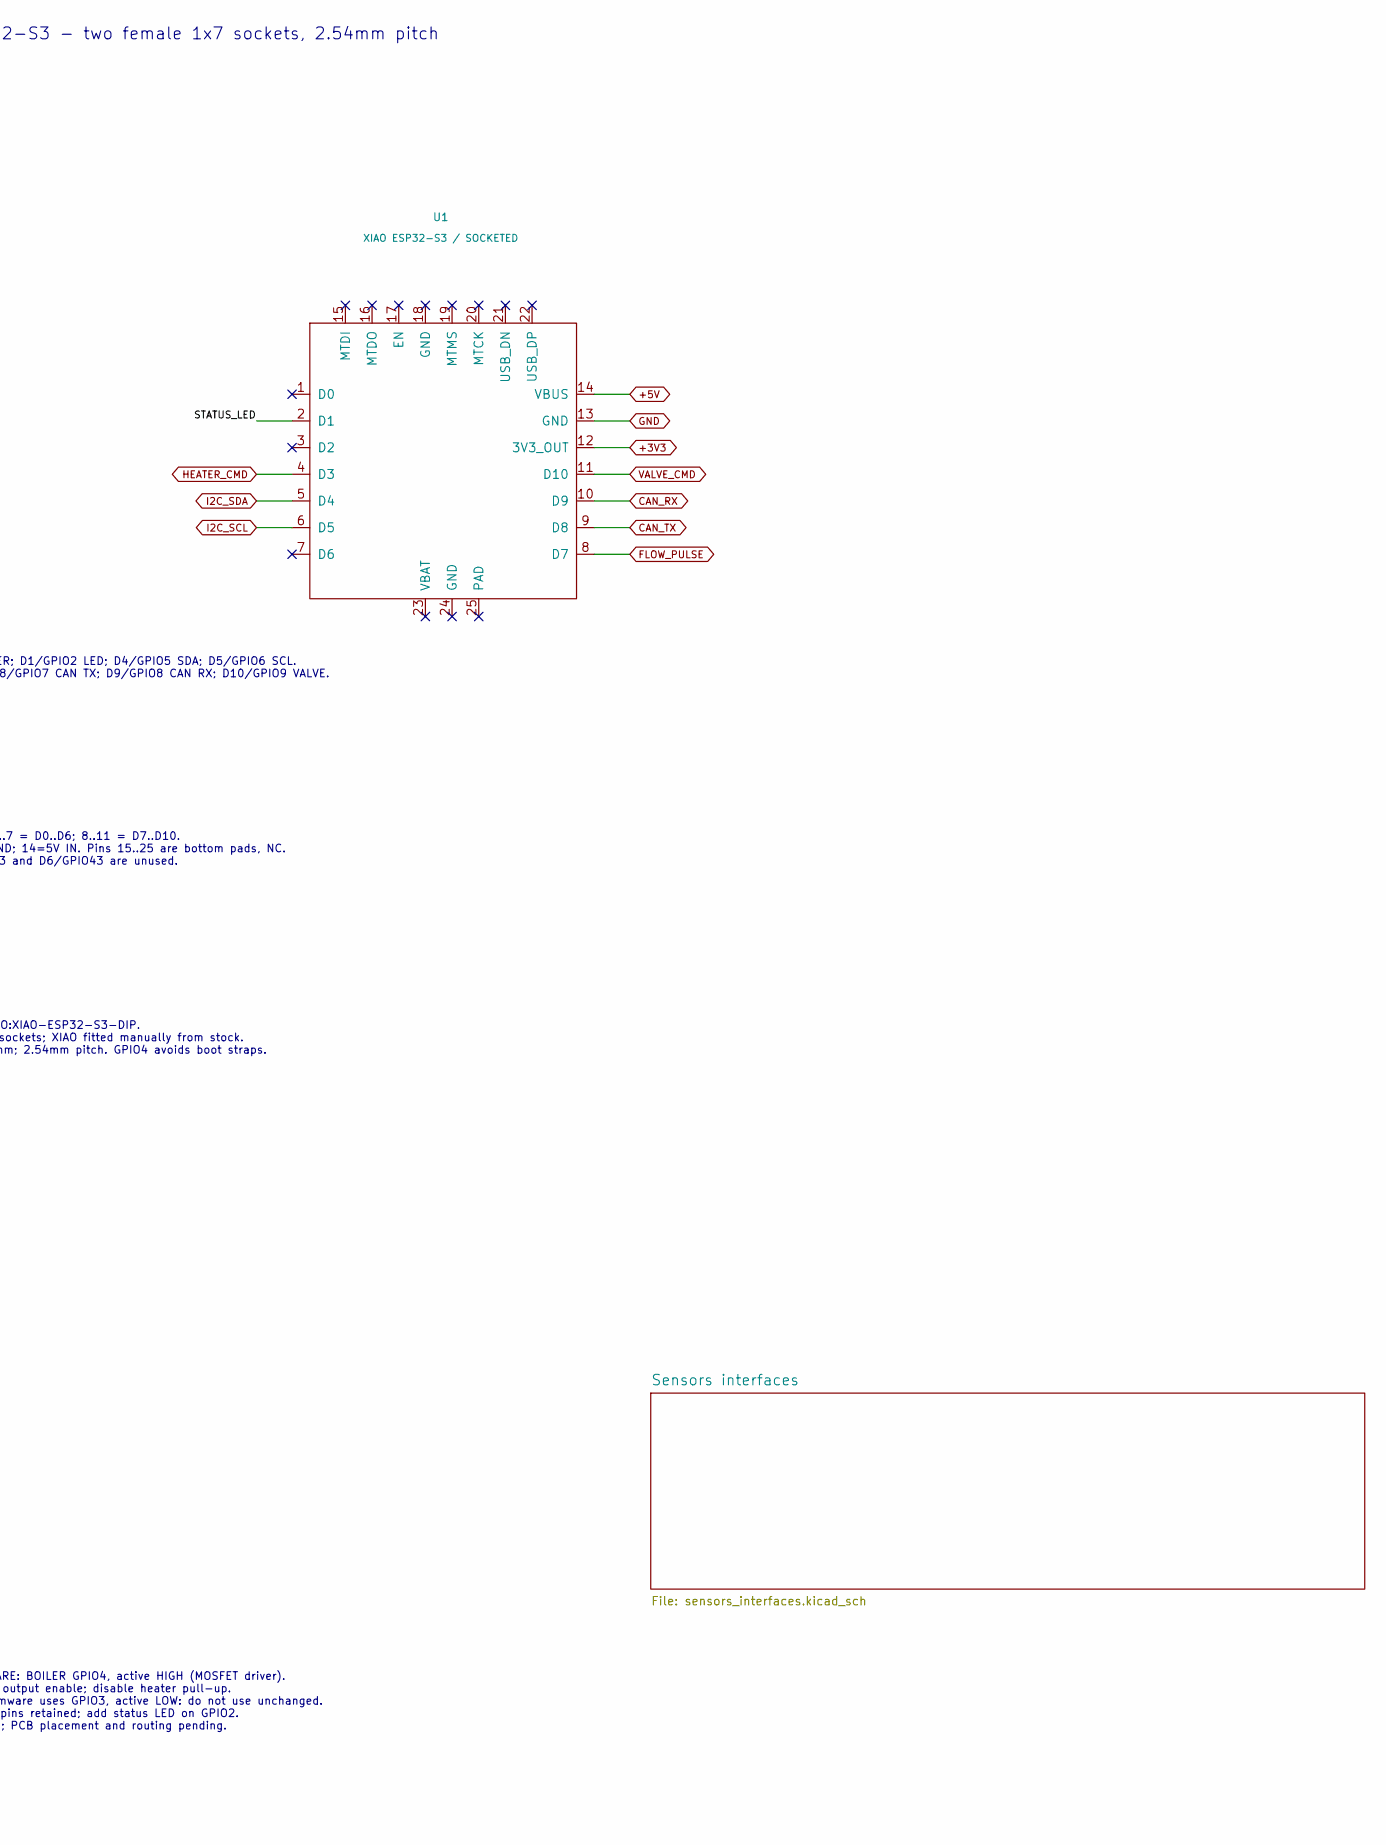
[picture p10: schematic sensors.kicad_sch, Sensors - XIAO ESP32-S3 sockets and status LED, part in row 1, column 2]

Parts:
D2: GREEN / STATUS; LED_0805_2012Metric; MPN KT-0805G; LCSC C2297
J1: 5V POWER; JST_XH_B2B-XH-A_1x02_P2.50mm_Vertical; MPN B2B-XH-A(LF)(SN); LCSC C158012
R25: 1k; R_0603_1608Metric; MPN 0603WAF1001T5E; LCSC C21190
U1: XIAO ESP32-S3 / SOCKETED; XIAO-ESP32-S3-DIP; MPN Seeed Studio XIAO ESP32-S3

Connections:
+3V3: U1.12 (3V3_OUT); also elsewhere on the board
+5V: J1.2, U1.14 (VBUS); also elsewhere on the board
/STATUS_LED: R25.1, U1.2 (D1)
/STATUS_LED_A: D2.2 (A), R25.2
CAN_RX: U1.10 (D9); also elsewhere on the board
CAN_TX: U1.9 (D8); also elsewhere on the board
FLOW_PULSE: U1.8 (D7); also elsewhere on the board
GND: D2.1 (K), J1.1, U1.13 (GND); also elsewhere on the board
HEATER_CMD: U1.4 (D3); also elsewhere on the board
I2C_SCL: U1.6 (D5); also elsewhere on the board
I2C_SDA: U1.5 (D4); also elsewhere on the board
VALVE_CMD: U1.11 (D10); also elsewhere on the board

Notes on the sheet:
1. POWER - external regulated 5V / XIAO onboard 3.3V regulator
J1 feeds XIAO 5V and the existing 5V interfaces. XIAO 3V3 supplies CAN VIO, I2C, TMP102 and FLOW pull-up. USB-C, LDO, BOOT and RESET are on the removable XIAO. Disconnect external J1 power before USB flashing.
3V3 PWR_FLAG represents the regulator output on the XIAO.
2. XIAO ESP32-S3 - two female 1x7 sockets, 2.54mm pitch
U1: D3/GPIO4 BOILER; D1/GPIO2 LED; D4/GPIO5 SDA; D5/GPIO6 SCL. D7/GPIO44 FLOW; D8/GPIO7 CAN TX; D9/GPIO8 CAN RX; D10/GPIO9 VALVE.
Seeed numbering: 1..7 = D0..D6; 8..11 = D7..D10. 12=3V3 OUT; 13=GND; 14=5V IN. Pins 15..25 are bottom pads, NC. D0/GPIO1, D2/GPIO3 and D6/GPIO43 are unused.
Footprint: Seeed_XIAO:XIAO-ESP32-S3-DIP. Fit two female 1x7 sockets; XIAO fitted manually from stock. Row spacing 15.24mm; 2.54mm pitch. GPIO4 avoids boot straps.
3. STATUS LED - GPIO2 / D1, HIGH = ON
Existing green LED and 1k resistor retained.
FUTURE PCB FIRMWARE: BOILER GPIO4, active HIGH (MOSFET driver). Preload LOW before output enable; disable heater pull-up. Current HW-399 firmware uses GPIO3, active LOW: do not use unchanged. Other existing XIAO pins retained; add status LED on GPIO2. Firmware unchanged; PCB placement and routing p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

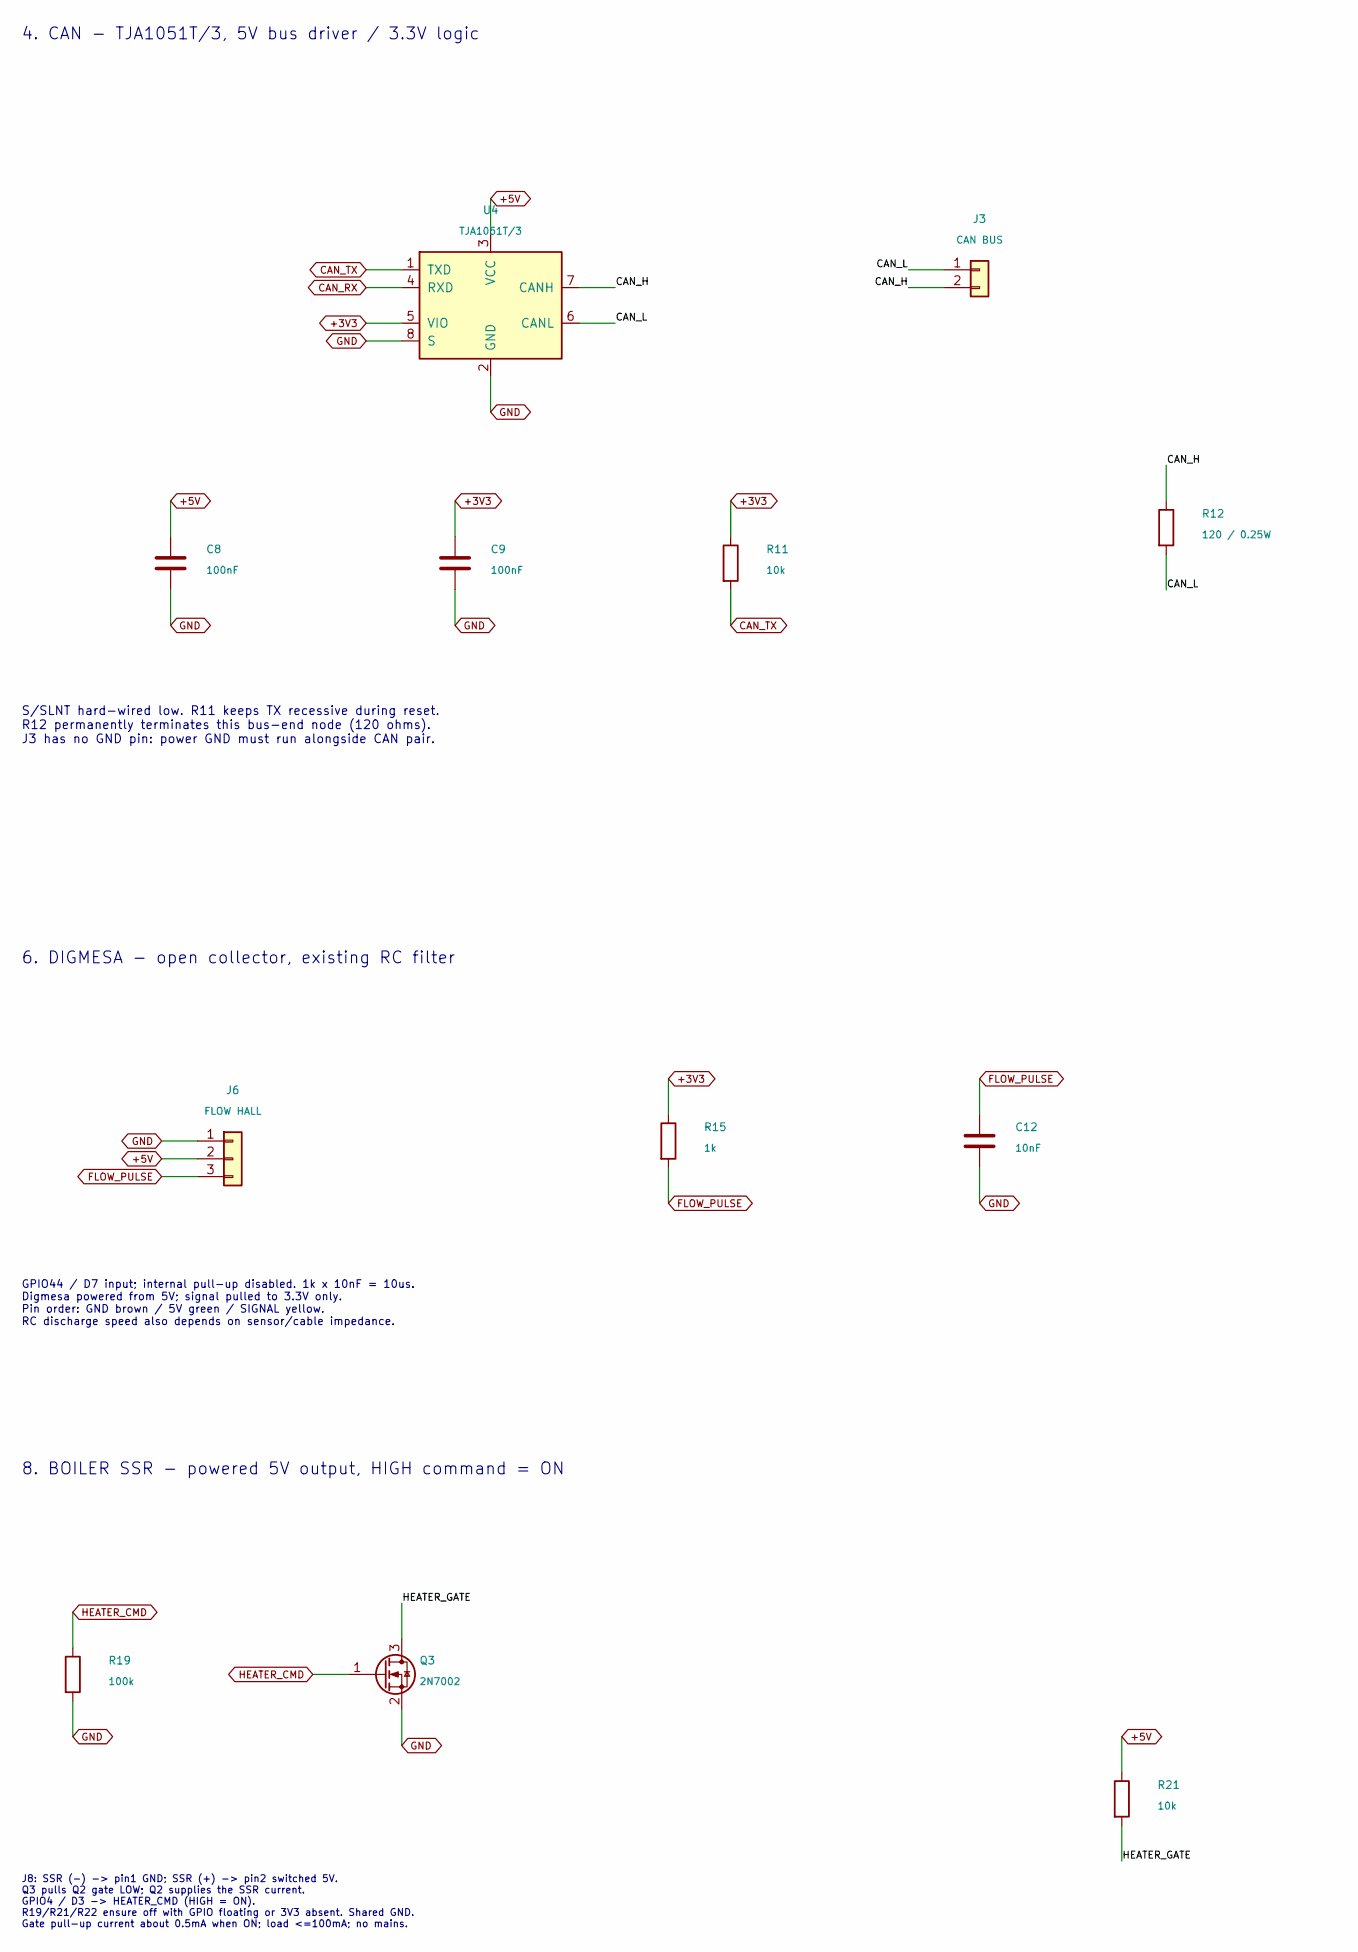
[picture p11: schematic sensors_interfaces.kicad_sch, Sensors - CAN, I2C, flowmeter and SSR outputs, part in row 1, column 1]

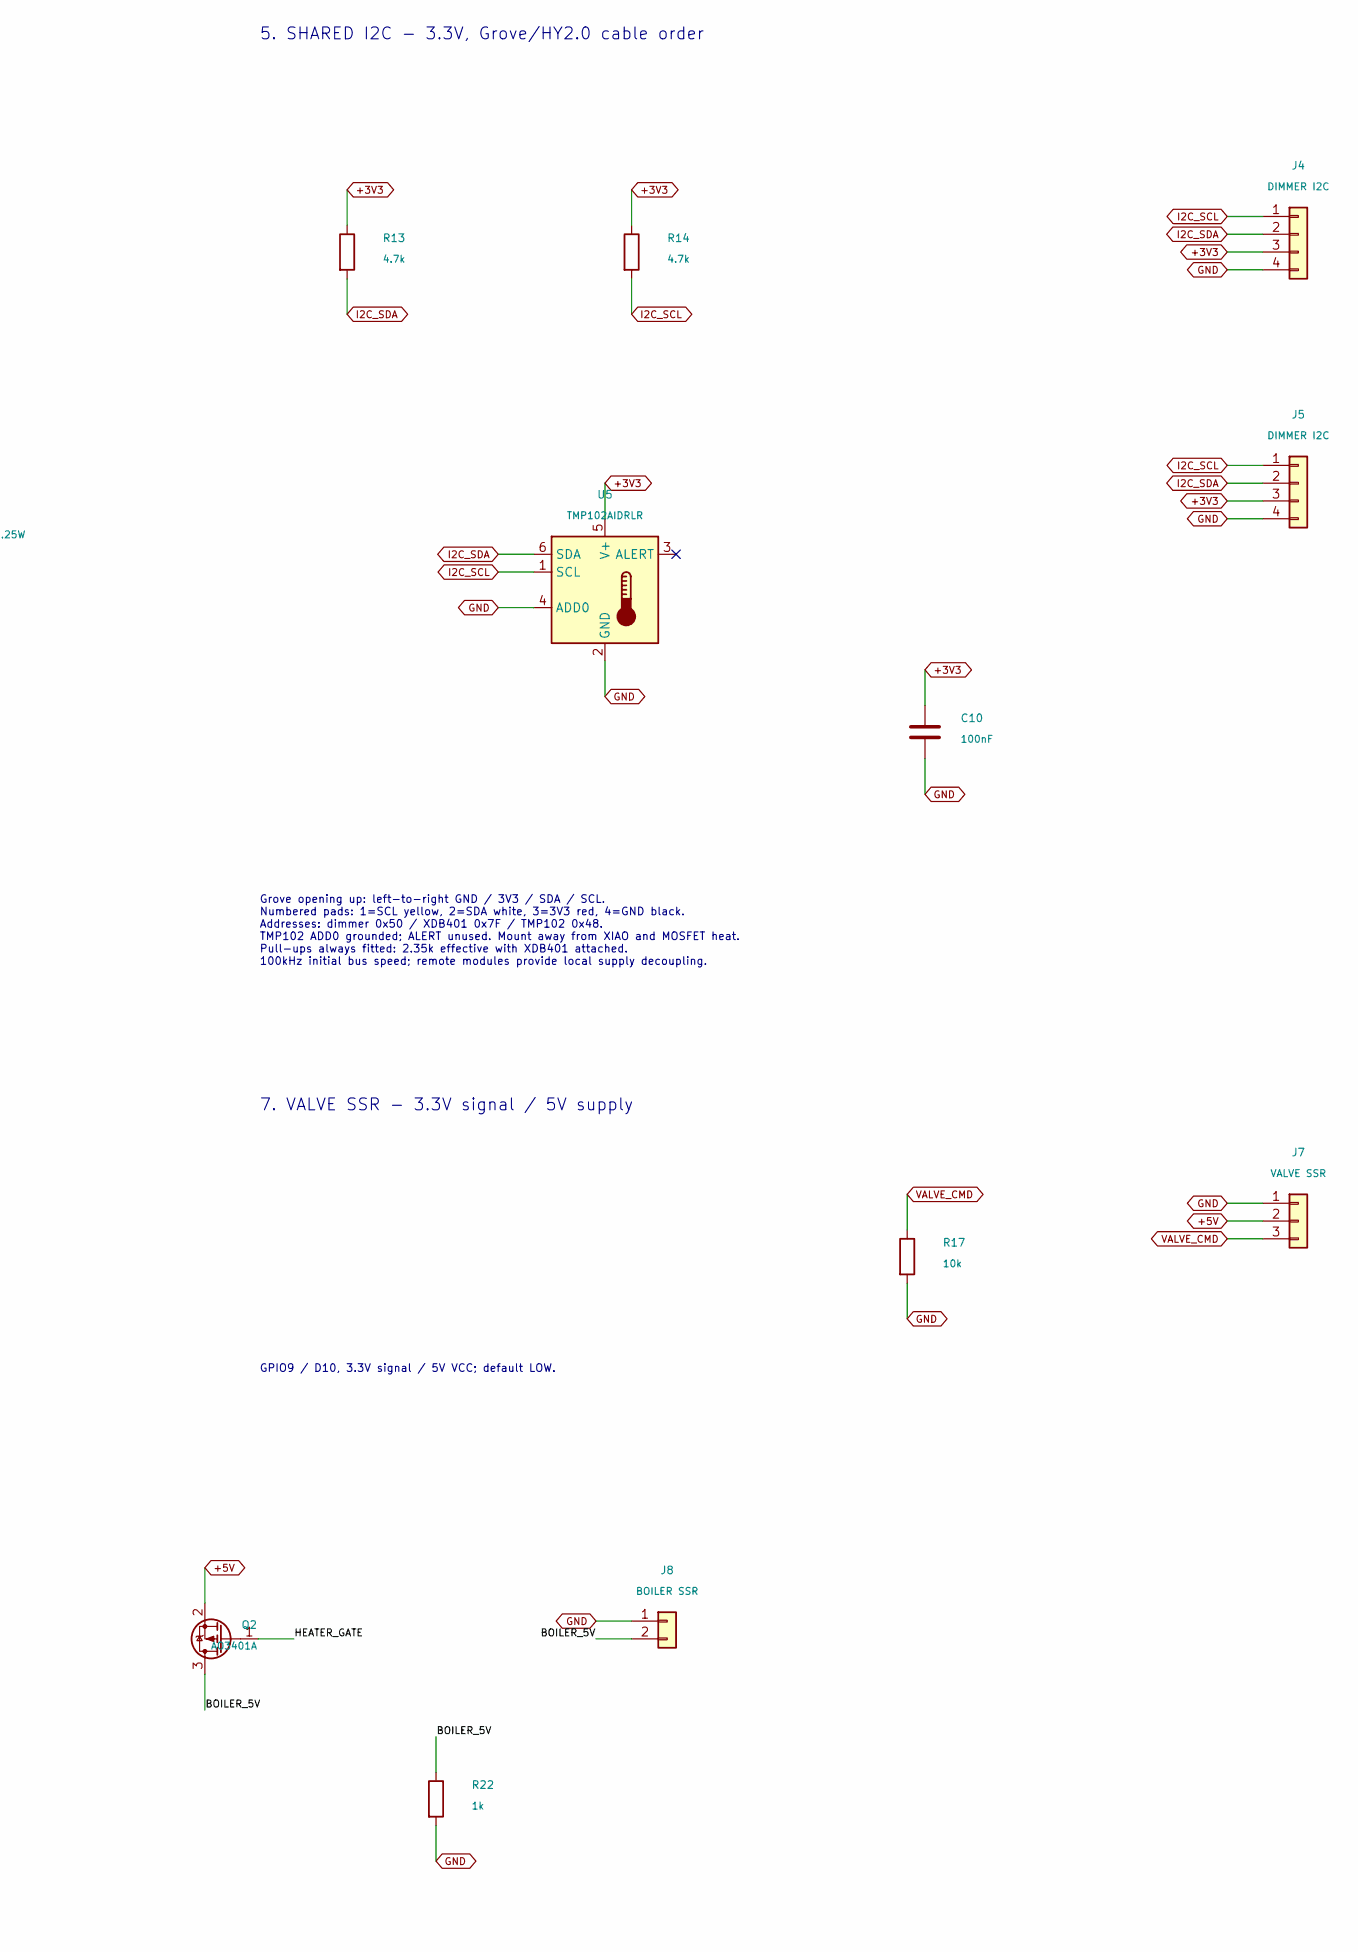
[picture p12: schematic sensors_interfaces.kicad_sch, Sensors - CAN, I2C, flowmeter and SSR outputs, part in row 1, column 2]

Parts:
C8, C9, C10: 100nF; C_0603_1608Metric; MPN CC0603KRX7R9BB104; LCSC C14663
C12: 10nF; C_0603_1608Metric; MPN 0603B103K500NT; LCSC C57112
J3: CAN BUS; JST_XH_B2B-XH-A_1x02_P2.50mm_Vertical; MPN B2B-XH-A(LF)(SN); LCSC C158012
J4, J5: DIMMER I2C; CONN-TH_HY-4A; MPN HY-4A; LCSC C722737
J6: FLOW HALL; JST_XH_B3B-XH-A_1x03_P2.50mm_Vertical; MPN B3B-XH-A(LF)(SN); LCSC C144394
J7: VALVE SSR; JST_XH_B3B-XH-A_1x03_P2.50mm_Vertical; MPN B3B-XH-A(LF)(SN); LCSC C144394
J8: BOILER SSR; JST_XH_B2B-XH-A_1x02_P2.50mm_Vertical; MPN B2B-XH-A(LF)(SN); LCSC C158012
Q2: AO3401A; SOT-23; MPN AO3401A; LCSC C15127
Q3: 2N7002; SOT-23; MPN 2N7002; LCSC C8545
R11, R17, R21: 10k; R_0603_1608Metric; MPN 0603WAF1002T5E; LCSC C25804
R12: 120 / 0.25W; R_1206_3216Metric; MPN 1206W4F1200T5E; LCSC C17909
R13, R14: 4.7k; R_0603_1608Metric; MPN 0603WAF4701T5E; LCSC C23162
R15, R22: 1k; R_0603_1608Metric; MPN 0603WAF1001T5E; LCSC C21190
R19: 100k; R_0603_1608Metric; MPN 0603WAF1003T5E; LCSC C25803
U4: TJA1051T/3; SOIC-8_3.9x4.9mm_P1.27mm; MPN TJA1051T/3/1J; LCSC C38695
U5: TMP102AIDRLR; SOT-563; MPN TMP102AIDRLR; LCSC C99269

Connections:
+3V3: C9.1, C10.1, J4.3, J5.3, R11.1, R13.1, R14.1, R15.1, U4.5 (VIO), U5.5 (V+); also elsewhere on the board
+5V: C8.1, J6.2, J7.2, Q2.2 (S), R21.1, U4.3 (VCC); also elsewhere on the board
/Sensors interfaces/BOILER_5V: J8.2, Q2.3 (D), R22.1
/Sensors interfaces/CAN_H: J3.2, R12.1, U4.7 (CANH)
/Sensors interfaces/CAN_L: J3.1, R12.2, U4.6 (CANL)
/Sensors interfaces/HEATER_GATE: Q2.1 (G), Q3.3 (D), R21.2
CAN_RX: U4.4 (RXD); also elsewhere on the board
CAN_TX: R11.2, U4.1 (TXD); also elsewhere on the board
FLOW_PULSE: C12.1, J6.3, R15.2; also elsewhere on the board
GND: C8.2, C9.2, C10.2, C12.2, J4.4, J5.4, J6.1, J7.1, J8.1, Q3.2 (S), R17.2, R19.2, R22.2, U4.2 (GND), U4.8 (S), U5.2 (GND), U5.4 (ADD0); also elsewhere on the board
HEATER_CMD: Q3.1 (G), R19.1; also elsewhere on the board
I2C_SCL: J4.1, J5.1, R14.2, U5.1 (SCL); also elsewhere on the board
I2C_SDA: J4.2, J5.2, R13.2, U5.6 (SDA); also elsewhere on the board
VALVE_CMD: J7.3, R17.1; also elsewhere on the board

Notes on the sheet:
8. BOILER SSR - powered 5V output, HIGH command = ON
5. SHARED I2C - 3.3V, Grove/HY2.0 cable order
4. CAN - TJA1051T/3, 5V bus driver / 3.3V logic
6. DIGMESA - open collector, existing RC filter
Grove opening up: left-to-right GND / 3V3 / SDA / SCL. Numbered pads: 1=SCL yellow, 2=SDA white, 3=3V3 red, 4=GND black. Addresses: dimmer 0x50 / XDB401 0x7F / TMP102 0x48. TMP102 ADD0 grounded; ALERT unused. Mount away from XIAO and MOSFET heat. Pull-ups always fitted: 2.35k effective with XDB401 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
GPIO9 / D10, 3.3V signal / 5V VCC; default LOW.
S/SLNT hard-wired low. R11 keeps TX recessive during reset. R12 permanently terminates this bus-end node (120 ohms). J3 has no GND pin: power GND must run alongside CAN pair.
7. VALVE SSR - 3.3V signal / 5V supply
J8: SSR (-) -> pin1 GND; SSR (+) -> pin2 switched 5V. Q3 pulls Q2 gate LOW; Q2 supplies the SSR current. GPIO4 / D3 -> HEATER_CMD (HIGH = ON). R19/R21/R22 ensure off with GPIO floating or 3V3 absent. Shared GND. Gate pull-up current about 0.5mA when ON; load <=100mA; no mains.
GPIO44 / D7 input; internal pull-up disabled. 1k x 10nF = 10us. Digmesa powered from 5V; signal pulled to 3.3V only. Pin order: GND brown / 5V green / SIGNAL yellow. RC discharge speed also depends on sensor/cable impedance.

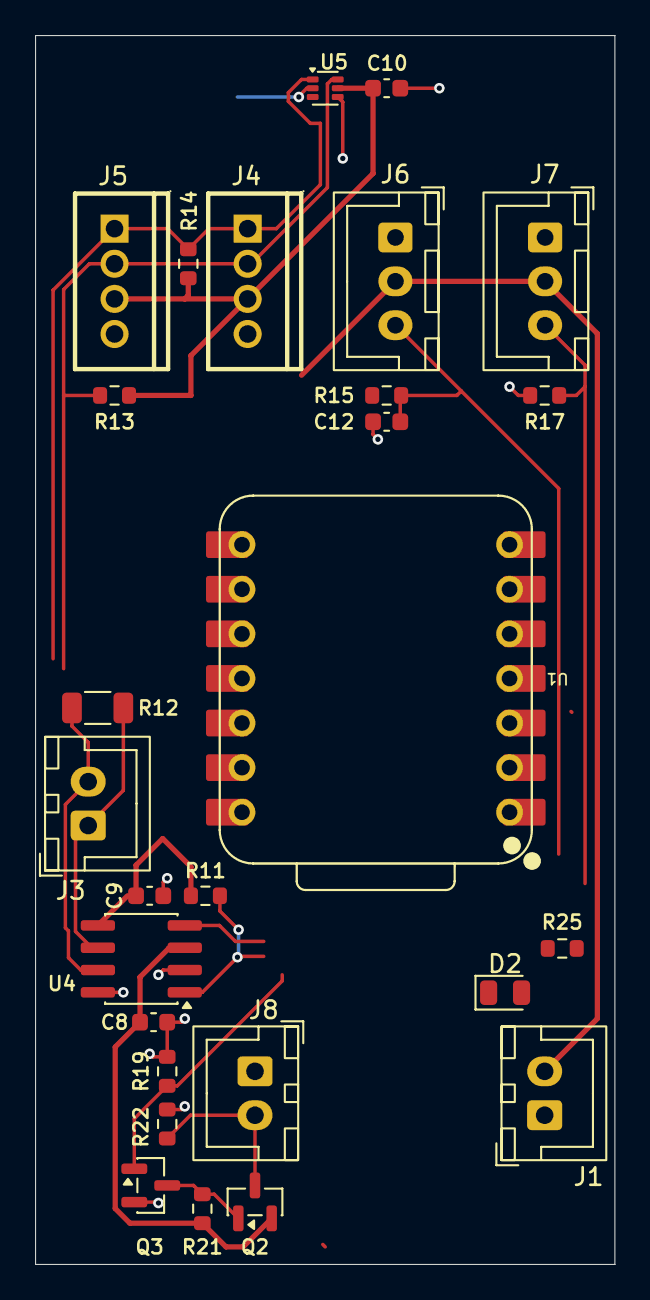
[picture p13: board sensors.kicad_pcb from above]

Board: 2 copper layers, 33.0 x 70.0 mm, 27 parts (0 on the bottom side), 16 nets.

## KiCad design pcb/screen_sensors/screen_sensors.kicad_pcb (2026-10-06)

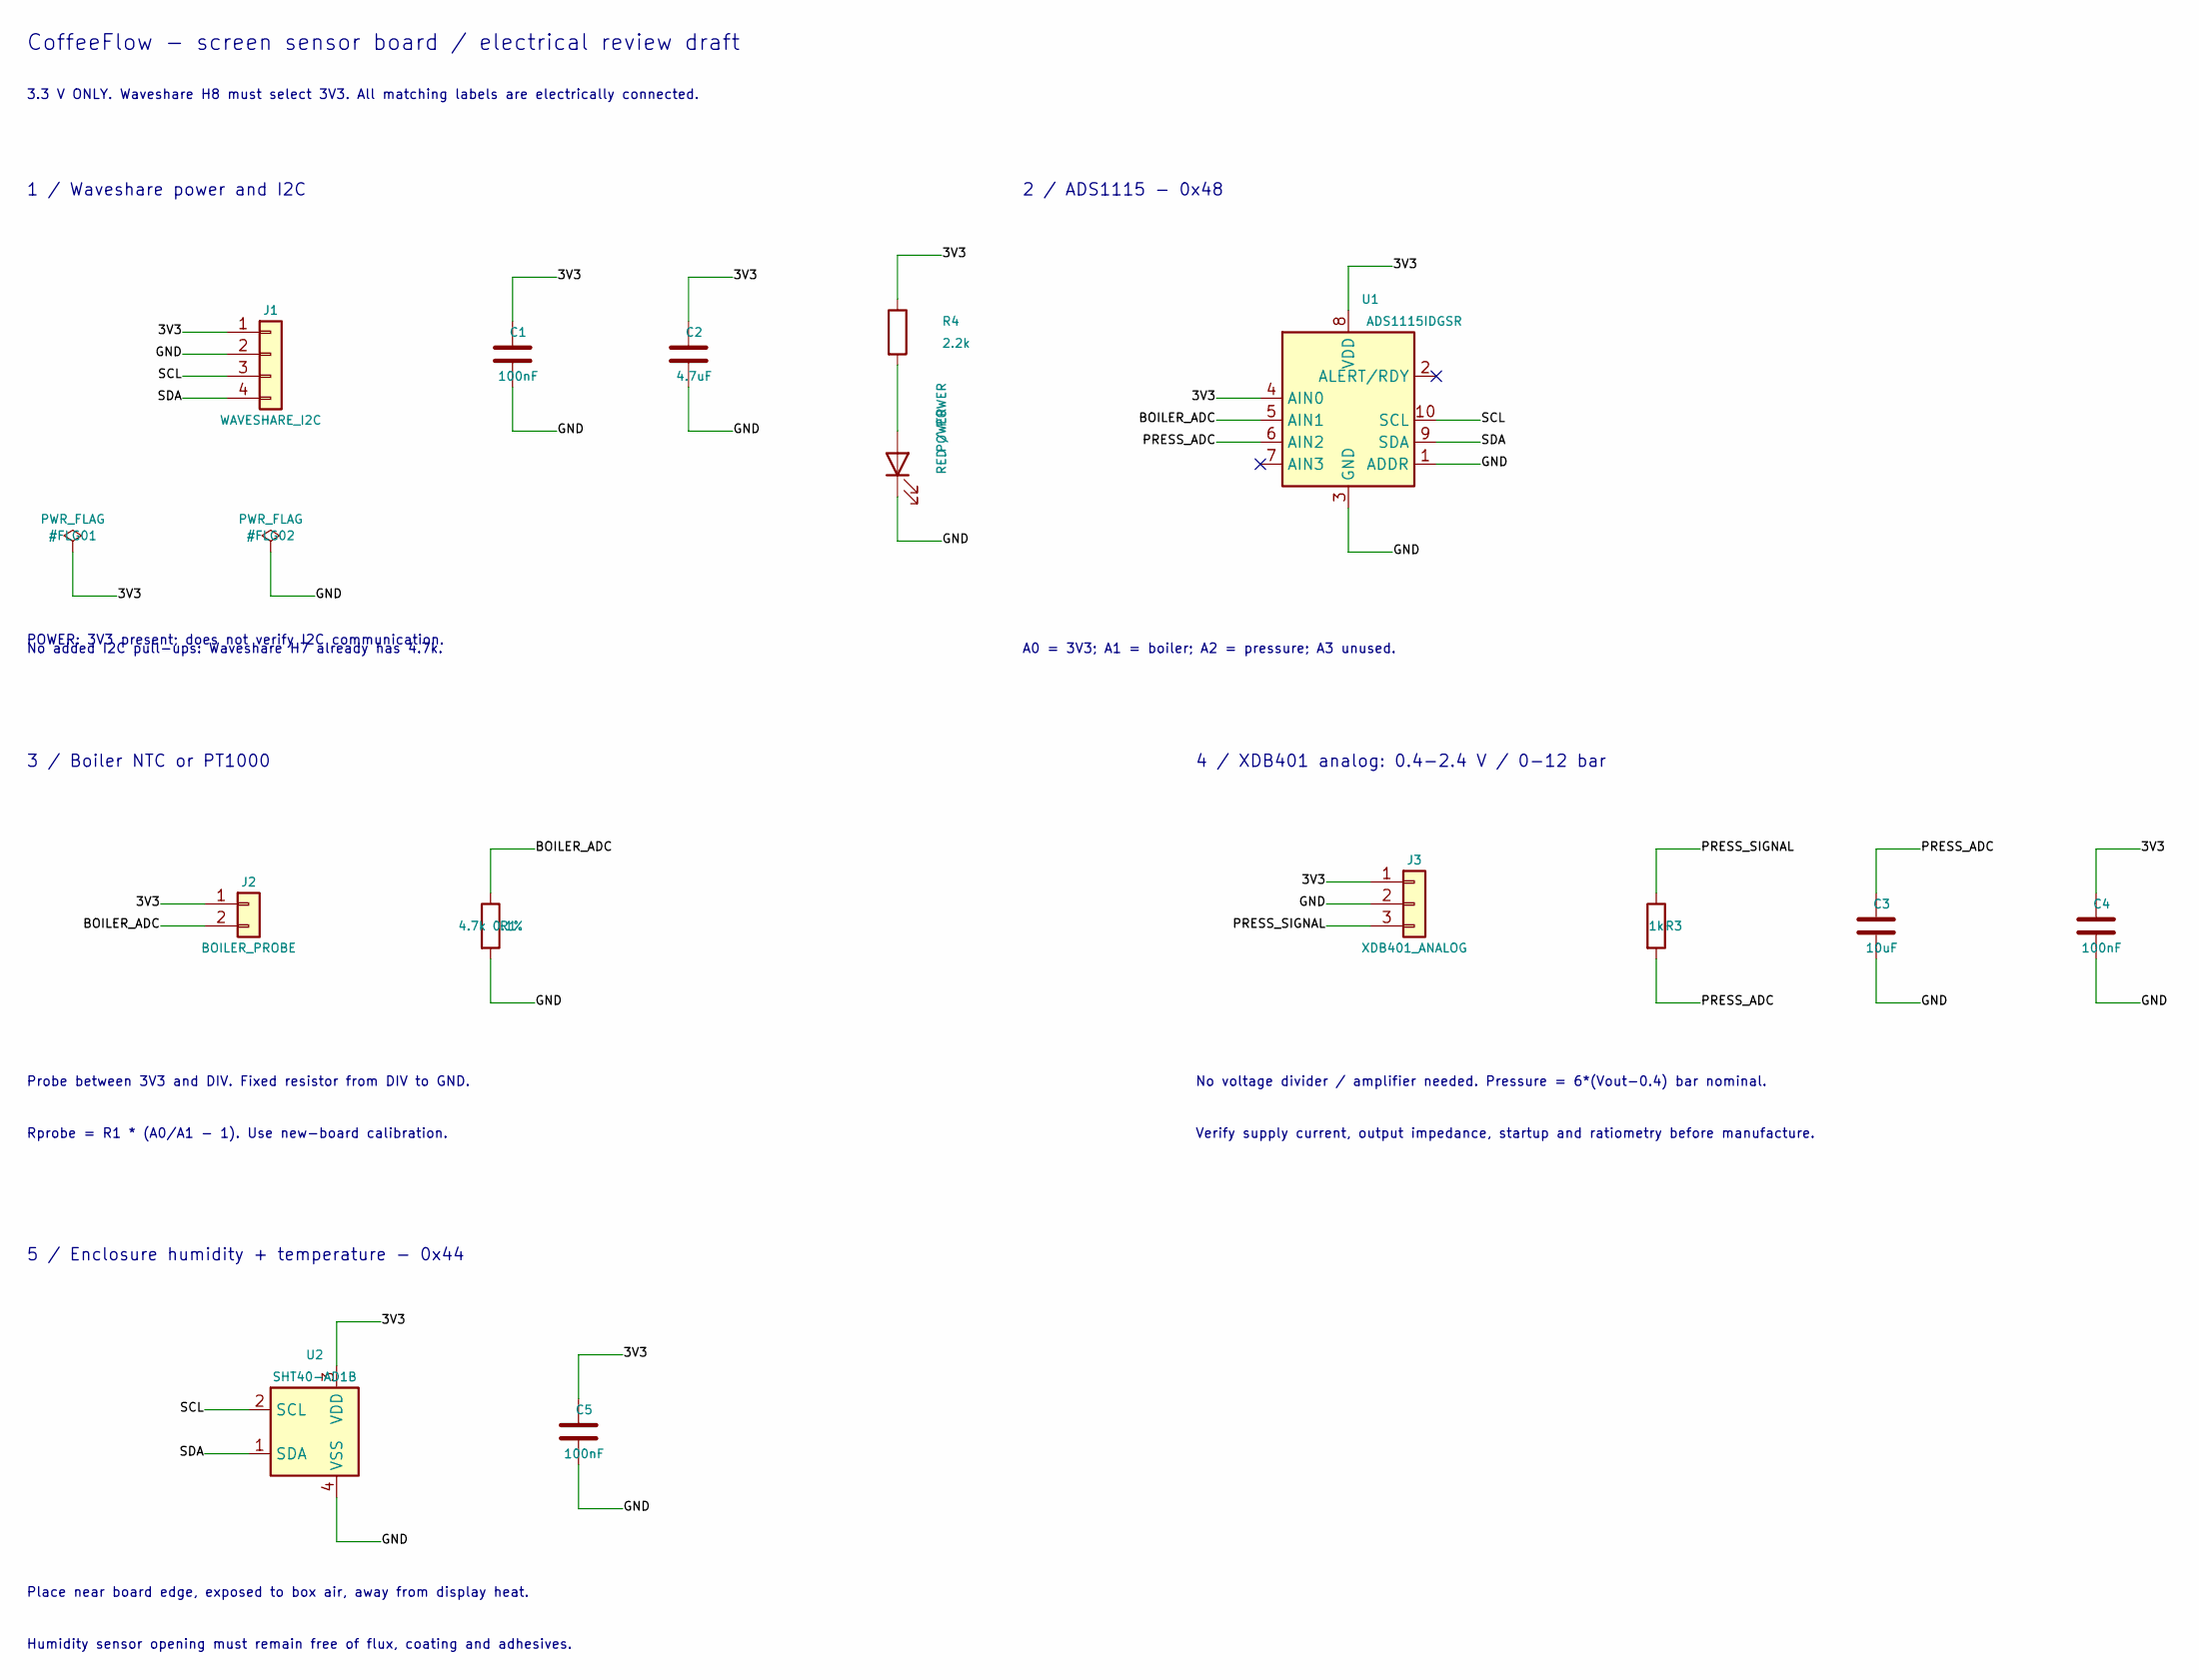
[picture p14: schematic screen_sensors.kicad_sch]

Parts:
C1, C4, C5: 100nF; C_0603_1608Metric; MPN CC0603KRX7R9BB104; LCSC C14663
C2: 4.7uF; C_0603_1608Metric; MPN CL10A475KO8NNNC; LCSC C19666
C3: 10uF; C_0603_1608Metric; MPN CL10A106KP8NNNC; LCSC C19702
J1: WAVESHARE_I2C; JST_XH_B4B-XH-A_1x04_P2.50mm_Vertical; MPN B4B-XH-A(LF)(SN); LCSC C144395
J2: BOILER_PROBE; JST_XH_B2B-XH-A_1x02_P2.50mm_Vertical; MPN B2B-XH-A-R(LF)(SN); LCSC C495685
J3: XDB401_ANALOG; JST_XH_B3B-XH-A_1x03_P2.50mm_Vertical; MPN B3B-XH-A(LF)(SN); LCSC C144394
POWER: RED / POWER; LED_0603_1608Metric; MPN KT-0603R; LCSC C2286
R1: 4.7k 0.1%; R_0603_1608Metric; MPN PTFR0603B4K70N9; LCSC C394547
R3: 1k; R_0603_1608Metric; MPN 0603WAF1001T5E; LCSC C21190
R4: 2.2k; R_0603_1608Metric; MPN 0603WAF2201T5E; LCSC C4190
U1: ADS1115IDGSR; TSSOP-10_3x3mm_P0.5mm; MPN ADS1115IDGSR; LCSC C37593
U2: SHT40-AD1B; Sensirion_DFN-4_1.5x1.5mm_P0.8mm_SHT4x_NoCentralPad; MPN SHT40-AD1B-R3; LCSC C2848306

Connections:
/3V3: C1.1, C2.1, C4.1, C5.1, J1.1, J2.1, J3.1, R4.1, U1.4 (AIN0), U1.8 (VDD), U2.3 (VDD)
/BOILER_ADC: J2.2, R1.1, U1.5 (AIN1)
/GND: C1.2, C2.2, C3.2, C4.2, C5.2, J1.2, J3.2, POWER.1 (K), R1.2, U1.1 (ADDR), U1.3 (GND), U2.4 (VSS)
/PRESS_ADC: C3.1, R3.2, U1.6 (AIN2)
/PRESS_SIGNAL: J3.3, R3.1
/SCL: J1.3, U1.10 (SCL), U2.2 (SCL)
/SDA: J1.4, U1.9 (SDA), U2.1 (SDA)
unnamed: POWER.2 (A), R4.2

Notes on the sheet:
CoffeeFlow - screen sensor board / electrical review draft
3.3 V ONLY. Waveshare H8 must select 3V3. All matching labels are electrically connected.
1 / Waveshare power and I2C
No added I2C pull-ups: Waveshare H7 already has 4.7k.
2 / ADS1115 - 0x48
A0 = 3V3; A1 = boiler; A2 = pressure; A3 unused.
3 / Boiler NTC or PT1000
Probe between 3V3 and DIV. Fixed resistor from DIV to GND.
Rprobe = R1 * (A0/A1 - 1). Use new-board calibration.
4 / XDB401 analog: 0.4-2.4 V / 0-12 bar
No voltage divider / amplifier needed. Pressure = 6*(Vout-0.4) bar nominal.
Verify supply current, output impedance, startup and ratiometry before manufacture.
5 / Enclosure humidity + temperature - 0x44
Place near board edge, exposed to box air, away from display heat.
Humidity sensor opening must remain free of flux, coating and adhesives.
POWER: 3V3 present; does not verify I2C communication.

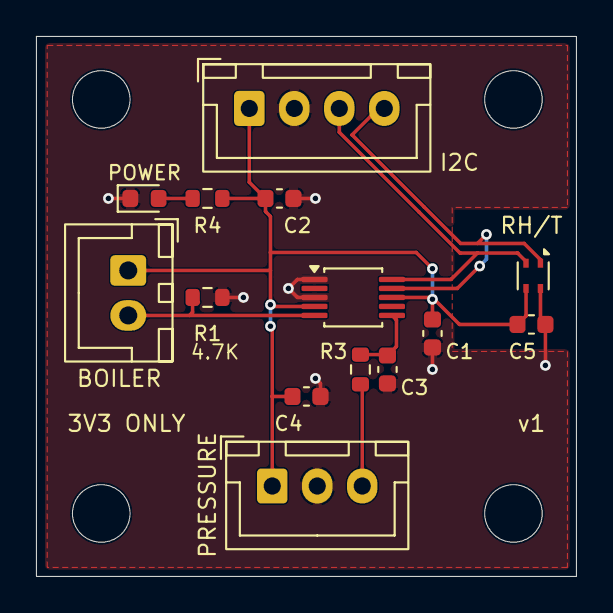
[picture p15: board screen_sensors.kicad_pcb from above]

Board: 2 copper layers, 30.0 x 30.0 mm, 18 parts (0 on the bottom side), 8 nets.

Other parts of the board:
H1, H2, H3, H4: M3; MountingHole_3.2mm_M3

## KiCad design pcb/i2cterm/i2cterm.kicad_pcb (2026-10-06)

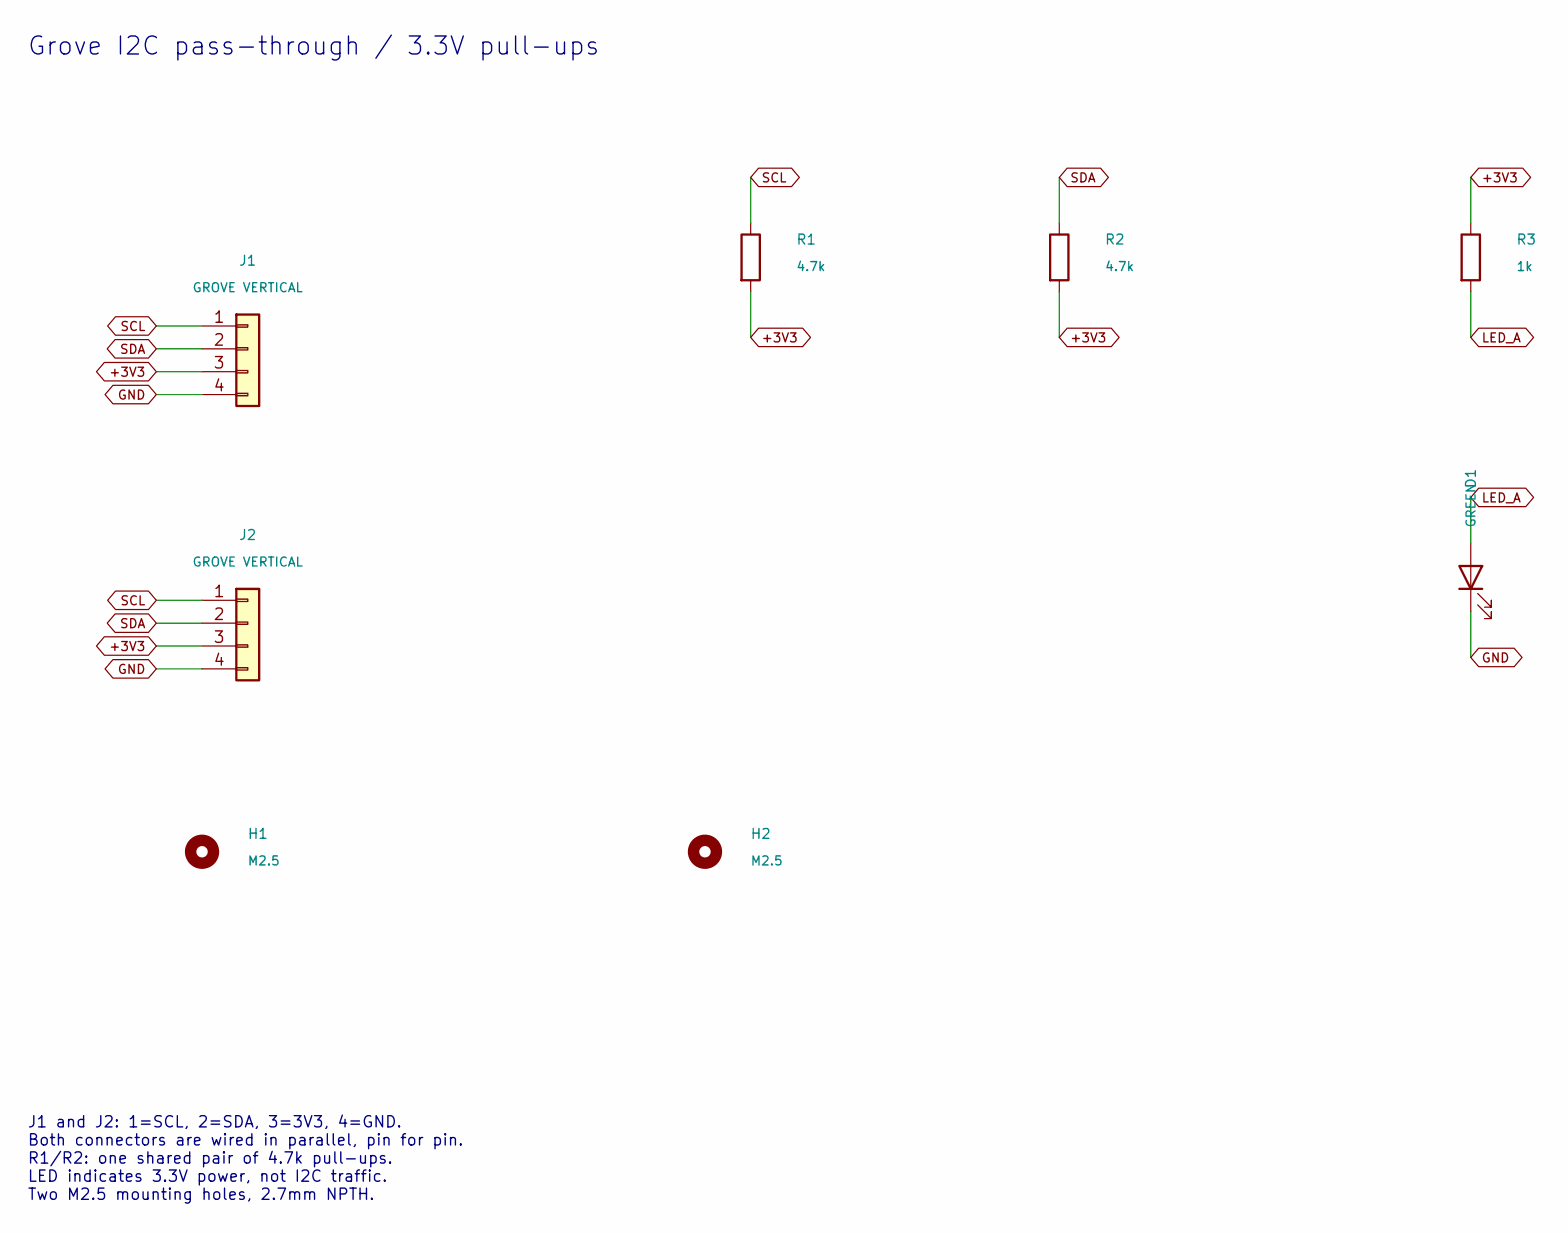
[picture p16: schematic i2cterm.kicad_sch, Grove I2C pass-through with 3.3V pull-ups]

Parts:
D1: GREEN; LED_0603_1608Metric; MPN KT-0603YG; LCSC C2289
H1, H2: M2.5; MountingHole_2.7mm_M2.5; MPN M2.5 / 2.7mm
J1, J2: GROVE VERTICAL; CONN-TH_HY-4A; MPN HY-4A; LCSC C722737
R1, R2: 4.7k; R_0603_1608Metric; MPN 0603 4.7k 1%; LCSC C23162
R3: 1k; R_0603_1608Metric; MPN 0603 1k 1%; LCSC C21190

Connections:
+3V3: J1.3, J2.3, R1.2, R2.2, R3.1
GND: D1.1 (K), J1.4, J2.4
LED_A: D1.2 (A), R3.2
SCL: J1.1, J2.1, R1.1
SDA: J1.2, J2.2, R2.1

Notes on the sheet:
Grove I2C pass-through / 3.3V pull-ups
J1 and J2: 1=SCL, 2=SDA, 3=3V3, 4=GND. Both connectors are wired in parallel, pin for pin. R1/R2: one shared pair of 4.7k pull-ups. LED indicates 3.3V power, not I2C traffic. Two M2.5 mounting holes, 2.7mm NPTH.

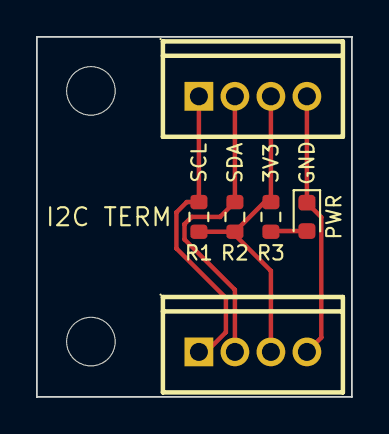
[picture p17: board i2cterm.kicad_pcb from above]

Board: 2 copper layers, 17.5 x 20.0 mm, 8 parts (0 on the bottom side), 5 nets.

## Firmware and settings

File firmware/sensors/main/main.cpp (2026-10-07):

// Module capteurs (XIAO ESP32-S3) — application capteurs, livrée par OTA.
//
// Socle phase 2 (bus, PING/PONG, LOG, RESET, machine à états de sécurité)
// plus le débitmètre Digmesa (GPIO, port R2) et le dimmer (I2C). Le canal
// pression (STATUS_PRESSURE) reste en place sans capteur : le XDB401 I2C a
// été remplacé par sa version analogique, lue par l'écran.

#include <cstring>

#include "driver/gpio.h"
#include "driver/i2c_master.h"
#include "driver/twai.h"
#include "esp_log.h"
#include "esp_ota_ops.h"
#include "esp_partition.h"
#include "esp_private/gpio.h"
#include "esp_system.h"
#include "esp_timer.h"
#include "freertos/FreeRTOS.h"
#include "freertos/semphr.h"
#include "freertos/task.h"

#include "common/crc.hpp"
#include "common/framing.hpp"
#include "common/messages.hpp"
#include "dimmer_zero_guard.h"
#include "heating_pwm.h"
#include "common/protocol.hpp"
#include "common/version.hpp"
#include "log_codes.hpp"

namespace {

constexpr const char* kTag = "sensors";

// Brochage — voir docs/firmware.md, "Module capteurs". GPIO natif de
// l'ESP32-S3, pas le D-number imprimé sur le silkscreen du Grove Shield
// XIAO (D8/D9/D10 ≠ GPIO8/9/10 : voir la note dans docs/cablage.md).
//
// Module Adafruit CAN Pal (TJA1051T/3, clone AliExpress) — SLNT reworké
// au GND, remplace le Unit CAN de
// contournement. Câblage Pal (docs/cablage.md) : TX → blanc → GPIO7,
// RX → jaune → GPIO8. Confirmé par self-test TWAI en boucle isolée
// (firmware/can-selftest, PINOUT_CANPAL 1) le 2026-09-09 : 17/17 PASS,
// tx_err=0 rx_err=0 bus_err=0.
constexpr gpio_num_t kGpioValve = GPIO_NUM_9;    // D10
constexpr gpio_num_t kGpioHeater = GPIO_NUM_3; // L2/D2, HW-399 IN4
constexpr int kHeaterActiveLevel = 0; // HW-399 OUT4 absorbe le courant du SSR
constexpr int kHeaterInactiveLevel = 1;
constexpr gpio_num_t kGpioCanTx = GPIO_NUM_7;  // D8
constexpr gpio_num_t kGpioCanRx = GPIO_NUM_8;  // D9

// Débitmètre Digmesa 932-9525-B, port R2 — voir docs/firmware.md,
// "Débitmètre". Front descendant déjà mis en forme 3,3 V par le filtre RC du
// shield (1 kΩ vers 3,3 V, 10 nF vers GND) : pull-up interne éteinte.
constexpr gpio_num_t kGpioFlow = GPIO_NUM_44;  // D7

// Bus I2C du dimmer. Ses seules pull-ups sont les 4,7 kΩ du module Grove
// branché sur le port R1, à la place de l'ancien XDB401 : ne pas activer les
// pull-ups internes ni en empiler d'autres.
constexpr gpio_num_t kGpioI2cSda = GPIO_NUM_5;  // D4
constexpr gpio_num_t kGpioI2cScl = GPIO_NUM_6;  // D5

// Dimmer RBDimmer/DimmerLink, même bus I2C (port L4) — voir docs/firmware.md,
// "Dimmer — pompe", et tmp/DimmerLink/04_I2C_COMMUNICATION.md (doc officielle
// du fabricant, trouvée et confirmée en bring-up le 2026-09-09 — le
// tests/test_rbi2c.py initial, sur un autre banc, avait la bonne carte de
// registres mais une table d'erreurs incomplète). 0x10 est la seule écriture
// du cycle d'infusion. 0x00 (STATUS, bit0=READY bit1=ERROR) est la source de
// vérité documentée pour l'état — pas le registre erreur seul, qui peut
// contenir des codes non documentés (0x01 observé en pratique, absent de la
// table officielle). Jamais écrire 0x01=SWITCH_UART au registre COMMAND
// (bascule UART, EEPROM) depuis ce firmware.
constexpr uint16_t kDimmerAddr = 0x50;
constexpr uint8_t kDimmerRegStatus = 0x00;
constexpr uint8_t kDimmerRegCommand = 0x01;
constexpr uint8_t kDimmerRegError = 0x02;
constexpr uint8_t kDimmerRegLevel = 0x10;
constexpr uint8_t kDimmerRegFreq = 0x20;  // informatif seulement, voir read_dimmer_health()
constexpr uint8_t kDimmerCmdReset = 0x01;
constexpr uint8_t kDimmerCmdRecalibrate = 0x02;
// Lu en dehors des écritures (voir tick_dimmer_health()), pour que les flags
// STATUS_ACTUATORS restent à jour même sans SET récent — contrairement au
// SSR, un écran qui ne rampe jamais le dimmer ne déclenche autrement aucune
// lecture I2C.
constexpr int64_t kDimmerHealthPeriodUs = 2000 * 1000;
// Marge avant un premier (et unique) essai de repli COMMAND=RECALIBRATE si
// le module reste "pas prêt" — voir dimmer_recalibrate() : le module calibre
// tout seul à la mise sous tension secteur, sans notre intervention
// (confirmé par un vrai power-cycle en bring-up le 2026-09-09, convergence
// naturelle observée sans jamais appeler RECALIBRATE). Volontairement large
// pour ne pas courir après une calibration déjà en cours.
constexpr int64_t kDimmerAutoRecalibrateDelayUs = 20 * 1000 * 1000;
// Plancher des publications STATUS_PRESSURE, pour qu'une requête mal formée
// ne sature pas le bus.
constexpr uint16_t kPressurePeriodFloorMs = 100;

// Sécurité — voir docs/firmware.md, section "Sécurité".
constexpr int64_t kLeaseDefaultUs = 500 * 1000;
constexpr int64_t kPresenceSilenceBeforeCheckUs = 1500 * 1000;
constexpr int64_t kPresencePingIntervalUs = 500 * 1000;
constexpr int64_t kPresenceCheckBailUs = 1500 * 1000;
constexpr int64_t kRuntimeLockoutUs = 60 * 1000 * 1000;
constexpr int64_t kRuntimeRearmGapUs = 2000 * 1000;
constexpr int64_t kTwaiCountersLogPeriodUs = 5000 * 1000;
constexpr int64_t kTickPeriodUs = 100 * 1000;
constexpr uint16_t kHeatingMaxDurationMs = 30000;
constexpr uint16_t kHeatingPowerLeaseMs = 1500;

// OTA. IDF ne redémarre
// jamais tout seul une image en PENDING_VERIFY : ce délai est le
// temporisateur d'invalidation explicite qui s'en charge. Réutilise le même
// signal que la présence (mark_presence(), donc un PING/PONG venu de
// l'écran/pont) comme preuve que l'image tourne assez pour parler au bus.
constexpr int64_t kOtaValidationTimeoutUs = 30 * 1000 * 1000;
constexpr size_t kFlashBlockSize = 2048;

// Verrou 60 s — tenu en mémoire RTC, ne survit qu'à un démarrage à froid.
// Voir docs/firmware.md §3 : une commande RESET venue du bus ne le lève pas.
constexpr uint32_t kRtcMagic = 0xC0FFEE02;
RTC_NOINIT_ATTR uint32_t s_rtc_magic;
RTC_NOINIT_ATTR bool s_lockout_active;

// État des actionneurs — RAM ordinaire, remis à zéro à chaque redémarrage,
// logiciel ou non (seul le verrou ci-dessus doit survivre).
bool g_valve_open = false;
// Vanne ouverte par MAINTENANCE_VALVE, pompe arrêtée. Son bail est
// g_lease_deadline_us, borné à common::kMaintenanceValveMaxMs ; elle n'entre
// pas dans le plafond 60 s (voir docs/firmware.md §3).
bool g_maintenance_valve = false;
bool g_heater_on = false;
int64_t g_heating_deadline_us = 0;
bool g_heating_power_mode = false;
uint16_t g_heating_power_permille = 0;
HeatingPwm g_heating_pwm;
portMUX_TYPE g_heating_lock = portMUX_INITIALIZER_UNLOCKED;
uint8_t g_pump_pct = 0;
DimmerZeroGuard g_dimmer_zero_guard;
// Santé dimmer, mise à jour à chaque écriture (voir apply_dimmer()) : reflète
// la dernière transaction I2C réelle, pas un état supposé.
bool g_dimmer_present = false;      // dernière transaction I2C a abouti (adresse ack)
bool g_dimmer_ready = false;        // STATUS bit0 (READY) à la dernière lecture
bool g_dimmer_error_active = false; // STATUS bit1 (ERROR) à la dernière lecture
int64_t g_lease_deadline_us = 0;  // 0 = pas de bail actif

// Plafond de marche continue — voir docs/firmware.md §3, "Rearmement".
int64_t g_run_start_us = 0;   // 0 = pas de marche en cours
int64_t g_off_since_us = 0;   // 0 = pas actuellement à l'arrêt

// Présence — voir docs/firmware.md §2.
int64_t g_last_presence_rx_us = 0;
int64_t g_presence_check_started_us = 0;
int64_t g_last_own_ping_us = 0;
uint8_t g_presence_probe_count = 0;
bool g_presence_lost = true;  // état de repos correct, carte seule sur la table

// Validation OTA.
bool g_ota_pending_verify = false;
int64_t g_ota_pending_since_us = 0;
bool g_ota_roundtrip_confirmed = false;
bool g_ota_screen_confirmed = false;

// Le mutex sérialise l'accès au bus I2C entre les tâches.
i2c_master_bus_handle_t g_i2c_bus = nullptr;
i2c_master_dev_handle_t g_dimmer_dev = nullptr;
SemaphoreHandle_t g_i2c_mutex = nullptr;
uint16_t g_pressure_period_ms = 0;  // 0 = arrêt, voir REQSTATUS
int64_t g_pressure_last_sent_us = 0;
// Aucun capteur de pression branché : flags à 0 (invalide), publié tel quel
// si un REQSTATUS le demande.
common::StatusPressurePayload g_last_pressure;

// Débitmètre — compteur incrémenté depuis l'ISR, lu depuis les tâches. Pas
// de mutex : lecture d'un uint32_t/int64_t alignés sur un cœur unique, la
// pire chose qui puisse arriver est un STATUS_FLOW envoyé avec l'horodatage
// de l'impulsion juste précédente ou juste suivante, jamais une valeur
// déchirée en pratique sur cette architecture.
volatile uint32_t g_flow_pulse_count = 0;
volatile int64_t g_flow_last_edge_us = 0;
// À 0,5 L/min et 2382 imp/L, deux fronts réels sont espacés d'environ
// 50,4 ms. Rejeter ceux qui arrivent plus tôt élimine les rebonds/ringing
// sans limiter le débit utile du Digmesa (spécifié à 0,40 L/min maximum).
constexpr int64_t kFlowMinEdgeIntervalMs = 50;
uint16_t g_flow_period_ms = 0;  // 0 = arrêt, voir REQSTATUS
int64_t g_flow_last_sent_us = 0;
uint16_t g_actuators_period_ms = 0;  // 0 = arrêt, voir REQSTATUS
int64_t g_actuators_last_sent_us = 0;
uint16_t g_heating_period_ms = 0;
int64_t g_heating_last_sent_us = 0;

void IRAM_ATTR flow_isr_handler(void*) {
  int64_t edge_us = esp_timer_get_time();
  if (g_flow_last_edge_us != 0 &&
      edge_us - g_flow_last_edge_us < kFlowMinEdgeIntervalMs * 1000) {
    return;
  }
  g_flow_pulse_count = g_flow_pulse_count + 1;
  g_flow_last_edge_us = edge_us;
}

// Flash — un seul transfert à la fois, pas de file d'attente. `partition`
// non nul == transfert en cours (BEGIN reçu, END/ABORT pas encore traité).
struct FlashState {
  const esp_partition_t* partition = nullptr;
  esp_ota_handle_t ota_handle = 0;
  uint32_t image_size = 0;
  uint32_t bytes_written = 0;
  uint16_t block_number = 0;  // nombre de blocs déjà acquittés
  uint16_t last_block_crc16 = 0;
  bool replay_ignored = false;
  uint8_t block_buf[kFlashBlockSize];
  size_t block_buf_len = 0;
  common::Crc32Incremental image_crc;
};
FlashState g_flash;

int64_t now_us() { return esp_timer_get_time(); }

void apply_valve() { gpio_set_level(kGpioValve, g_valve_open ? 1 : 0); }
// L'état PWM et la sortie SSR sont modifiés par la réception CAN et la tâche
// de sécurité : ils doivent avancer ensemble, sans appliquer un tick périmé.
void force_heating_off_locked() {
  g_heater_on = false;
  g_heating_deadline_us = 0;
  g_heating_power_mode = false;
  g_heating_power_permille = 0;
  g_heating_pwm.reset();
  gpio_set_level(kGpioHeater, kHeaterInactiveLevel);
}
void force_heating_off() {
  portENTER_CRITICAL(&g_heating_lock);
  force_heating_off_locked();
  portEXIT_CRITICAL(&g_heating_lock);
}

// Déclaration en avance : apply_dimmer() a besoin de send_log(), défini plus
// bas dans ce fichier avec les autres émetteurs.
void send_log(common::LogCode code, common::LogSeverity severity, uint16_t arg16, uint32_t arg32);
void send_status_actuators();
void force_actuators_off();

// Relit STATUS (0x00, bit0=READY bit1=ERROR — voir tmp/DimmerLink/
// 04_I2C_COMMUNICATION.md, doc officielle) et, informativement seulement,
// la fréquence secteur (0x20). Utilisée aussi bien après une écriture
// (apply_dimmer()) que périodiquement à vide (tick_dimmer_health()), pour
// que g_dimmer_present/ready/error_active restent à jour même sans SET
// récent. Transaction combinée (write pointeur + read en repeated-start,
// pas deux transactions séparées) — c'est ce que fait la doc officielle et
// tests/test_rbi2c.py (i2c.readfrom_mem()).
void read_dimmer_health() {
  const uint8_t reg_status = kDimmerRegStatus;
  uint8_t status_value = 0;

  xSemaphoreTake(g_i2c_mutex, portMAX_DELAY);
  esp_err_t err = i2c_master_transmit_receive(g_dimmer_dev, &reg_status, 1, &status_value, 1, pdMS_TO_TICKS(100));
  xSemaphoreGive(g_i2c_mutex);

  if (err != ESP_OK) {
    g_dimmer_present = false;
    g_dimmer_ready = false;
    g_dimmer_error_active = false;
    send_log(common::LogCode::kI2cError, common::LogSeverity::kError, kDimmerAddr, 0);
    return;
  }
  g_dimmer_present = true;
  g_dimmer_ready = (status_value & 0x01) != 0;
  g_dimmer_error_active = (status_value & 0x02) != 0;

  if (!g_dimmer_ready) {
    send_log(common::LogCode::kDimmerCalibrating, common::LogSeverity::kWarn, 0, 0);
  }
  if (g_dimmer_error_active) {
    const uint8_t reg_error = kDimmerRegError;
    uint8_t error_value = 0xFF;
    xSemaphoreTake(g_i2c_mutex, portMAX_DELAY);
    esp_err_t eerr = i2c_master_transmit_receive(g_dimmer_dev, &reg_error, 1, &error_value, 1, pdMS_TO_TICKS(100));
    xSemaphoreGive(g_i2c_mutex);
    send_log(common::LogCode::kDimmerError, common::LogSeverity::kError, eerr == ESP_OK ? error_value : 0xFFFF, 0);
  }

  // Fréquence secteur : purement informatif. Observée à 0 en continu sur ce
  // module même une fois READY=1 et sans ERROR (bring-up 2026-09-09), donc
  // pas fiable comme critère de "secteur détecté" malgré ce que documente
  // tmp/DimmerLink — journalisée pour diagnostic futur, jamais utilisée pour
  // piloter un flag.
  const uint8_t reg_freq = kDimmerRegFreq;
  uint8_t freq_value = 0;
  xSemaphoreTake(g_i2c_mutex, portMAX_DELAY);
  esp_err_t ferr = i2c_master_transmit_receive(g_dimmer_dev, &reg_freq, 1, &freq_value, 1, pdMS_TO_TICKS(100));
  xSemaphoreGive(g_i2c_mutex);
  send_log(common::LogCode::kDimmerMainsFreq, common::LogSeverity::kDebug, ferr == ESP_OK ? freq_value : 0xFFFF, 0);
}

// COMMAND=RECALIBRATE (0x02) : sans ça après une mise sous tension secteur
// tardive ou une correction de câblage, le module peut rester avec
// STATUS.READY=0 même une fois le secteur stable — confirmé en bring-up
// 2026-09-09 (STATUS passe de 0x32 à "ready=1,err=0" juste après ce
// recalibrate). Non fatal si le module n'est pas encore présent au boot.
void dimmer_recalibrate() {
  const uint8_t cmd[2] = {kDimmerRegCommand, kDimmerCmdRecalibrate};
  xSemaphoreTake(g_i2c_mutex, portMAX_DELAY);
  esp_err_t err = i2c_master_transmit(g_dimmer_dev, cmd, sizeof(cmd), pdMS_TO_TICKS(100));
  xSemaphoreGive(g_i2c_mutex);
  if (err != ESP_OK) {
    ESP_LOGW(kTag, "dimmer recalibrate échec: %s", esp_err_to_name(err));
  }
}

void on_dimmer_command_received(const uint8_t* data, size_t len) {
  common::DimmerCommandPayload payload;
  if (!common::DimmerCommandPayload::unpack(data, len, &payload)) return;

  // Une calibration/réinitialisation ne doit jamais coexister avec une
  // demande de pompe encore active, même si l'interface envoie par erreur la
  // commande pendant un cycle.
  force_actuators_off();
  const uint8_t cmd = payload.command == common::DimmerCommand::kReset
                          ? kDimmerCmdReset
                          : kDimmerCmdRecalibrate;
  const uint8_t write_command[2] = {kDimmerRegCommand, cmd};
  xSemaphoreTake(g_i2c_mutex, portMAX_DELAY);
  esp_err_t err = i2c_master_transmit(g_dimmer_dev, write_command, sizeof(write_command), pdMS_TO_TICKS(100));
  xSemaphoreGive(g_i2c_mutex);
  if (err != ESP_OK) {
    ESP_LOGW(kTag, "dimmer command 0x%02x échec: %s", cmd, esp_err_to_name(err));
    send_log(common::LogCode::kI2cError, common::LogSeverity::kError, kDimmerAddr, 0);
  }
  read_dimmer_health();
  send_status_actuators();
}

// Écrit le niveau courant sur le DimmerLink puis relit sa santé (STATUS,
// erreur si besoin, fréquence en informatif) — voir docs/firmware.md,
// "Dimmer — pompe".
bool apply_dimmer(uint8_t level) {
  const uint8_t write_level[2] = {kDimmerRegLevel, level};

  xSemaphoreTake(g_i2c_mutex, portMAX_DELAY);
  esp_err_t err = i2c_master_transmit(g_dimmer_dev, write_level, sizeof(write_level), pdMS_TO_TICKS(100));
  xSemaphoreGive(g_i2c_mutex);
  if (err != ESP_OK) {
    if (g_dimmer_present) {
      send_log(common::LogCode::kI2cError, common::LogSeverity::kError, kDimmerAddr, 0);
    }
    g_dimmer_present = false;
    g_dimmer_ready = false;
    g_dimmer_error_active = false;
    return false;
  }

  read_dimmer_health();
  return true;
}

void tick_dimmer_zero_guard() {
  // En maintenance, la pompe doit rester à zéro : la garde la réaffirme.
  g_dimmer_zero_guard.tick(now_us(), g_valve_open && !g_maintenance_valve, [] { return apply_dimmer(0); });
}

// Lecture périodique à vide (sans écrire de niveau) — voir le commentaire de
// kDimmerHealthPeriodUs : sans elle, un dimmer jamais commandé (aucun SET
// reçu depuis le boot) resterait avec des flags STATUS_ACTUATORS figés à
// leur valeur initiale.
void tick_dimmer_health() {
  static int64_t s_last_us = 0;
  static bool s_recalibrate_sent = false;
  int64_t t = now_us();
  if (t - s_last_us < kDimmerHealthPeriodUs) return;
  s_last_us = t;
  read_dimmer_health();

  // Repli, une seule fois par épisode "pas prêt" : voir le commentaire de
  // dimmer_recalibrate() sur la race avec la calibration propre au module.
  // g_dimmer_present exigé : pas de repli tant qu'on n'a jamais eu de vraie
  // réponse I2C (câblage/alimentation, pas un problème de calibration).
  if (g_dimmer_present && !g_dimmer_ready && !s_recalibrate_sent && t > kDimmerAutoRecalibrateDelayUs) {
    s_recalibrate_sent = true;
    dimmer_recalibrate();
  }
  if (g_dimmer_ready) {
    s_recalibrate_sent = false;  // réarme pour une future coupure/reprise secteur
  }
}

void send_message(common::MessageType type, common::Dest dest, const uint8_t* data, uint8_t dlc) {
  common::CanId id{type, dest, common::Node::kSensors};
  twai_message_t msg{};
  msg.identifier = common::encode_can_id(id);
  msg.data_length_code = dlc;
  if (dlc > 0) {
    std::memcpy(msg.data, data, dlc);
  }
  esp_err_t err = twai_transmit(&msg, pdMS_TO_TICKS(50));
  if (err != ESP_OK) {
    ESP_LOGW(kTag, "twai_transmit type=0x%02x échec: %s", static_cast<int>(type), esp_err_to_name(err));
  }
}

void send_log(common::LogCode code, common::LogSeverity severity, uint16_t arg16 = 0, uint32_t arg32 = 0) {
  common::LogPayload payload;
  payload.code = static_cast<uint8_t>(code);
  payload.severity = static_cast<uint8_t>(severity);
  payload.arg16 = arg16;
  payload.arg32 = arg32;
  common::Frame f = payload.pack();
  send_message(common::MessageType::kLog, common::Dest::kBroadcast, f.data(), 8);
}

void send_pong() {
  common::PongPayload payload;
  payload.node = common::Node::kSensors;
  payload.version_major = common::kFirmwareVersionMajor;
  payload.version_minor = common::kFirmwareVersionMinor;
  payload.version_patch = common::kFirmwareVersionPatch;
  payload.uptime_s = static_cast<uint32_t>(now_us() / 1000000);
  common::Frame f = payload.pack();
  send_message(common::MessageType::kPong, common::Dest::kScreen, f.data(), 8);
}

void send_ping(common::Dest dest) {
  common::PingPayload payload;
  payload.node = common::Node::kSensors;
  payload.version_major = common::kFirmwareVersionMajor;
  payload.version_minor = common::kFirmwareVersionMinor;
  payload.version_patch = common::kFirmwareVersionPatch;
  payload.uptime_s = static_cast<uint32_t>(now_us() / 1000000);
  common::Frame f = payload.pack();
  send_message(common::MessageType::kPing, dest, f.data(), 8);
}
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
extern "C" void app_main() {
  // La protection pendant le reset exige aussi une vérification matérielle.
  // Précharge le latch à l'état inactif avant d'activer le driver de sortie.
  gpio_set_level(kGpioHeater, kHeaterInactiveLevel);
  gpio_config_t heater_cfg{};
  heater_cfg.pin_bit_mask = 1ULL << kGpioHeater;
  heater_cfg.mode = GPIO_MODE_OUTPUT;
  heater_cfg.pull_down_en = GPIO_PULLDOWN_DISABLE;
  heater_cfg.pull_up_en = GPIO_PULLUP_ENABLE;
  heater_cfg.intr_type = GPIO_INTR_DISABLE;
  ESP_ERROR_CHECK(gpio_config(&heater_cfg));
  gpio_set_level(kGpioHeater, kHeaterInactiveLevel);
  // GPIO 10 tenu bas avant toute autre initialisation, y compris le CAN —
  // voir docs/firmware.md, "Le SSR est bas au boot, avant toute
  // initialisation du CAN."
  gpio_config_t ssr_cfg{};
  ssr_cfg.pin_bit_mask = 1ULL << kGpioValve;
  ssr_cfg.mode = GPIO_MODE_OUTPUT;
  ssr_cfg.pull_up_en = GPIO_PULLUP_DISABLE;
  ssr_cfg.pull_down_en = GPIO_PULLDOWN_DISABLE;
  ssr_cfg.intr_type = GPIO_INTR_DISABLE;
  gpio_config(&ssr_cfg);
  gpio_set_level(kGpioValve, 0);

  init_lockout_state();

  // NEW ou PENDING_VERIFY.
  // Ne jamais valider l'image tout de suite ici — tick_ota_validation() ne
  // le fait qu'après un PING/PONG confirmé sur le bus, ou rollback au bout
  // de kOtaValidationTimeoutUs.
  const esp_partition_t* running = esp_ota_get_running_partition();
  esp_ota_img_states_t ota_state;
  if (running != nullptr && esp_ota_get_state_partition(running, &ota_state) == ESP_OK &&
      (ota_state == ESP_OTA_IMG_PENDING_VERIFY || ota_state == ESP_OTA_IMG_NEW)) {
    g_ota_pending_verify = true;
    g_ota_pending_since_us = now_us();
  }

  twai_general_config_t g_config = TWAI_GENERAL_CONFIG_DEFAULT(kGpioCanTx, kGpioCanRx, TWAI_MODE_NORMAL);
  twai_timing_config_t t_config = TWAI_TIMING_CONFIG_500KBITS();
  twai_filter_config_t f_config = TWAI_FILTER_CONFIG_ACCEPT_ALL();
  ESP_ERROR_CHECK(twai_driver_install(&g_config, &t_config, &f_config));
  ESP_ERROR_CHECK(twai_start());

  int64_t t0 = now_us();
  g_last_presence_rx_us = t0 - kPresenceSilenceBeforeCheckUs;  // en attente, pas encore vu de pair
  g_last_own_ping_us = 0;

  // Identité au démarrage : le PING versionné informe immédiatement l'écran
  // et le PONG reçu participe à la validation d'une image OTA.
  send_ping(common::Dest::kScreen);

  send_log(common::LogCode::kBoot, common::LogSeverity::kInfo);
  if (g_ota_pending_verify) {
    send_log(common::LogCode::kOtaPendingVerify, common::LogSeverity::kInfo);
  }
  ESP_LOGI(kTag, "boot, version %d.%d.%d, verrou=%s", common::kFirmwareVersionMajor,
           common::kFirmwareVersionMinor, common::kFirmwareVersionPatch,
           s_lockout_active ? "actif" : "libre");

  init_i2c();
  init_flow();

  xTaskCreate(twai_rx_task, "twai_rx", 4096, nullptr, 10, nullptr);
  xTaskCreate(safety_task, "safety", 4096, nullptr, 5, nullptr);
  xTaskCreate(pressure_task, "pressure", 4096, nullptr, 4, nullptr);

  send_log(common::LogCode::kReady, common::LogSeverity::kInfo);
}

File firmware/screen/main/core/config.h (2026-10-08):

// Configuration utilisateur persistante. Les calibrations sont compilées dans
// calibration_machine.h : elles ne passent ni par NVS ni par /config.
#pragma once

#include <cstdint>

namespace core {

inline constexpr uint16_t kConfigSchemaVersion = 10;
inline constexpr float kMinimumBrewTemperatureC = 50.0f;
inline constexpr float kMaximumBrewTemperatureC = 100.0f;
inline constexpr float kMaximumBrewPreheatTimeS = 15.0f;
inline constexpr float kBrewTemperatureToleranceC = 1.0f;
// Sous cette puissance, la pompe ne maintient plus une pression d'infusion
// sûre. Cette borne est distincte des puissances de remplissage et de purge.
inline constexpr uint8_t kMinimumBrewPumpPct = 50;

// Le bit 1 désignait la sortie de pré-infusion par pression (schéma 7 et
// antérieurs). Il est retiré, mais les bits suivants gardent leur valeur
// pour que l'encodage NVS et l'interface restent lisibles.
enum class PreinfusionMode : uint8_t {
  kNone = 0,
  kTime = 1 << 0,
  kWeight = 1 << 2,
};
inline constexpr uint8_t kPreinfusionModeMask = 0x05;

constexpr PreinfusionMode operator|(PreinfusionMode lhs, PreinfusionMode rhs) {
  return static_cast<PreinfusionMode>(static_cast<uint8_t>(lhs) | static_cast<uint8_t>(rhs));
}

constexpr PreinfusionMode operator&(PreinfusionMode lhs, PreinfusionMode rhs) {
  return static_cast<PreinfusionMode>(static_cast<uint8_t>(lhs) & static_cast<uint8_t>(rhs));
}

constexpr bool has_preinfusion_mode(PreinfusionMode modes, PreinfusionMode mode) {
  return (modes & mode) != PreinfusionMode::kNone;
}
enum class RampdownMode : uint8_t { kNone, kTime, kWeight, kPressureDrop };

struct Config {
  uint16_t version = kConfigSchemaVersion;
  uint32_t revision = 0;
  float target_weight_g = 36.0f;
  uint16_t target_time_s = 28;
  float target_pressure_bar = 9.0f;
  float brew_temperature_c = 90.0f;
  bool heating_enabled = true;
  float brew_preheat_time_s = 2.5f;
  // Secours : à 75 % de pompe, 10 s admettent ≈ 34 ml, au-delà du volume
  // à 1 bar de toutes les captures (23,5 à 30,7 ml).
  uint16_t filling_time_s = 10;
  // Pression absolue qui termine le remplissage : headspace plein et galette
  // mouillée.
  float filling_pressure_bar = 1.0f;
  uint8_t filling_pump_pct = 100;
  PreinfusionMode preinfusion_mode = PreinfusionMode::kTime;
  uint16_t preinfusion_time_s = 4;
  uint8_t preinfusion_pump_pct = 35;
  RampdownMode rampdown_mode = RampdownMode::kNone;
  float rampdown_lead_time_s = 3.0f;
  float rampdown_lead_weight_g = 4.0f;
  float rampdown_pressure_drop_bar = 1.0f;
  uint8_t brew_pump_pct = 100;
  uint8_t purge_pump_pct = 100;
  uint16_t purge_max_s = 20;
  uint16_t dim_after_s = 240;
  uint16_t standby_after_s = 1800;
  // Recherche et connexion BLE de la sonde SCACE. Désactivée par défaut : la
  // sonde ne sert qu'aux campagnes de mesure.
  bool scace_enabled = false;
};

// `profiles` et les courbes de calibration ne sont délibérément pas encodés
// dans le blob v1. Ils auront leur propre sous-format versionné lorsqu'ils
// existeront ; ne pas leur réserver des tableaux arbitraires aujourd'hui.
inline constexpr bool kProfilesSupported = false;

enum class ConfigStatus : uint8_t { kOk, kVersionMismatch, kStaleRevision, kInvalidValue, kStorageError, kBusy };
struct ConfigResult { ConfigStatus status = ConfigStatus::kOk; const char* field = nullptr; };

// Initialise/charge les deux emplacements transactionnels NVS. À appeler
// après nvs_flash_init(), avant tout consommateur de configuration.
void config_init();
Config get_config();
ConfigResult apply_config(const Config& candidate, uint32_t expected_revision);
ConfigResult reset_config();

}  // namespace core

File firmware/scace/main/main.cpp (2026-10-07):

// Sonde SCACE : NTC du puck lue par un ADS1115 sur le port A du Core2.
//
// Le pont est alimenté par le 5 V du port A, que le firmware laisse coupé au
// démarrage : la sonde ne chauffe que lorsqu'on la mesure. La touche A bascule
// l'alimentation. La touche C, maintenue une seconde, éteint le Core2.
//
// Deux tâches. La tâche de mesure, prioritaire et seule à toucher le bus du
// port A (Ex_I2C), lit l'ADS1115 à 10 Hz et envoie chaque mesure sur la
// console et en notification BLE (ble_server). La boucle principale garde les
// touches, la puce d'alimentation sur le bus interne et l'écran, redessiné à
// 4 Hz : un dessin complet prend environ 75 ms et ne retarde plus la mesure.

#include <M5Unified.h>

#include <atomic>
#include <cmath>
#include <cstdint>
#include <cstdio>
#include <deque>

#include "ble_server.h"
#include "freertos/semphr.h"

namespace {

// Version de l'image, affichée en haut de l'écran. Indépendante de celle des
// cartes de la machine (common/version.hpp) ; à incrémenter à chaque image
// flashée.
constexpr char kFirmwareVersion[] = "0.3.1";

// Pont : 3,3 V -> R fixe -> A1 -> NTC -> GND, A0 sur le 3,3 V.
// Recalée au point de glace : elle absorbe la R fixe réelle et la tolérance
// de ±1 % sur R25, car seul leur rapport compte. Ce n'est donc pas la valeur
// lue au multimètre (989 Ω).
constexpr double kFixedOhm = 999.5;
// EPCOS B57861S0103F, courbe R/T 8016 : Steinhart–Hart ajustée sur la table
// du fabricant de -10 à 110 °C, 1/T = A + B ln R + C (ln R)^3, R en ohms.
// Écart à la table ≤ 0,02 K, l'ordre de son arrondi. La loi Beta avec
// B25/100 lisait +0,77 K à 0 °C et -0,39 K à 60 °C.
constexpr double kShA = 1.12476949e-03;
constexpr double kShB = 2.34824463e-04;
constexpr double kShC = 8.50854659e-08;
// Écart de B à la valeur nominale (tolérance ±0,3 %, soit ±12 K), recalé au
// point d'ébullition. Référencé à 0 °C pour ne pas déplacer le point de glace.
constexpr double kBetaShiftK = 0.0;
constexpr double kKelvinAt0C = 273.15;

constexpr uint32_t kI2cHz = 400000;
constexpr float kVoltsPerCode = 4.096f / 32768.0f;
// Un ADS1115 dont le 3,3 V vient d'apparaître répond en moins d'une
// milliseconde ; 50 ms couvrent aussi la montée du LDO et du boost du Core2.
constexpr uint32_t kPowerSettleMs = 50;
constexpr uint32_t kSearchRetryMs = 500;
constexpr uint32_t kSamplePeriodMs = 100;
// 128 SPS : 7,8 ms par conversion. Au-delà de 50 ms, l'ADS ne convertit plus.
constexpr uint32_t kConversionTimeoutMs = 50;
constexpr uint32_t kWindowMs = 5000;
// Une paire A0 puis A1 tient en quatre tours de 5 ms.
constexpr uint32_t kMeasureLoopMs = 5;
constexpr uint32_t kUiLoopMs = 10;
constexpr uint32_t kRenderPeriodMs = 250;
constexpr uint32_t kBatteryPeriodMs = 2000;
// Un effleurement de C ne doit pas éteindre l'appareil en pleine mesure.
constexpr uint32_t kShutdownHoldMs = 1000;
// Sans mesure, une trame « pas de mesure » par seconde dit aux centraux que
// la sonde est là mais que le pont est coupé ou l'ADS absent.
constexpr uint32_t kIdleFrameMs = 1000;
// La tâche de mesure libère le bus en un tour ; au-delà, on coupe quand même.
constexpr TickType_t kReleaseTimeout = pdMS_TO_TICKS(200);

constexpr uint16_t kMuxA0 = 4;
constexpr uint16_t kMuxA1 = 5;

enum class Phase { kOff, kSettling, kSearching, kIdle, kConvA0, kConvA1 };
enum class Status { kNone, kOk, kOpen, kShorted };
enum class Request { kNone, kOn, kOff };

struct Sample {
  int16_t a0 = 0;
  int16_t a1 = 0;
  float ohm = NAN;
  float celsius = NAN;
  Status status = Status::kNone;
};

struct WindowPoint {
  uint32_t ms;
  float celsius;
};

// Ce que l'écran lit de la mesure, copié sous verrou.
struct Snapshot {
  Phase phase = Phase::kOff;
  uint8_t address = 0;
  uint32_t i2c_errors = 0;
  Sample sample;
  bool has_window = false;
  float lo = NAN;
  float hi = NAN;
};

uint32_t now_ms() { return static_cast<uint32_t>(esp_timer_get_time() / 1000); }

// --- Échanges entre les deux tâches ---------------------------------------

std::atomic<Request> g_request{Request::kNone};
SemaphoreHandle_t g_bus_released = nullptr;
portMUX_TYPE g_snapshot_lock = portMUX_INITIALIZER_UNLOCKED;
Snapshot g_snapshot;

// --- État de la tâche de mesure --------------------------------------------

Phase g_phase = Phase::kOff;
uint32_t g_phase_ms = 0;
uint32_t g_last_sample_start_ms = 0;
uint8_t g_address = 0;
bool g_bus_open = false;
int16_t g_pending_a0 = 0;
Sample g_sample;
std::deque<WindowPoint> g_window;
uint32_t g_i2c_errors = 0;
uint16_t g_frame_seq = 0;
uint32_t g_last_frame_ms = 0;

// --- État de la boucle principale ------------------------------------------

bool g_bridge_on = false;
bool g_power_refused = false;
int32_t g_battery_pct = -1;
bool g_charging = false;
M5Canvas g_canvas(&M5.Display);

void enter(Phase phase, uint32_t now) {
  g_phase = phase;
  g_phase_ms = now;
}

double sh_inv_kelvin(double ln_r) { return kShA + kShB * ln_r + kShC * ln_r * ln_r * ln_r; }

// R = R_table(T) · exp(ΔB · (1/T − 1/273,15)) : on retire le décalage de B
// avant la table. 1/T dépend de lui-même, mais à peine (pente ~0,003) :
// trois itérations suffisent largement.
double celsius_from_ohm(double ohm) {
  const double ln_r = std::log(ohm);
  double inv_t = sh_inv_kelvin(ln_r);
  for (int i = 0; i < 3; ++i) inv_t = sh_inv_kelvin(ln_r - kBetaShiftK * (inv_t - 1.0 / kKelvinAt0C));
  return 1.0 / inv_t - kKelvinAt0C;
}

Sample evaluate(int16_t a0, int16_t a1) {
  Sample s;
  s.a0 = a0;
  s.a1 = a1;
  // Ratiométrique : le rail se simplifie, seuls les codes comptent.
  // NTC ouverte : A1 rejoint A0. NTC en court-circuit : A1 tombe à 0.
  if (a0 <= 0 || a1 >= a0 - 4) {
    s.status = Status::kOpen;
    return s;
  }
  if (a1 <= 4) {
    s.status = Status::kShorted;
    return s;
  }
  const double ohm = kFixedOhm * a1 / (a0 - a1);
  s.ohm = static_cast<float>(ohm);
  s.celsius = static_cast<float>(celsius_from_ohm(ohm));
  s.status = Status::kOk;
  return s;
}

bool start_conversion(uint16_t mux) {
  // OS=1, MUX=Ax-GND, PGA=±4,096 V, single-shot, 128 SPS, comparateur coupé.
  const uint16_t config = static_cast<uint16_t>(0x8000 | (mux << 12) | 0x0200 | 0x0100 | 0x0080 | 0x0003);
  const uint8_t bytes[] = {static_cast<uint8_t>(config >> 8), static_cast<uint8_t>(config)};
  return M5.Ex_I2C.writeRegister(g_address, 0x01, bytes, sizeof(bytes), kI2cHz);
}
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

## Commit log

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2026-08-15 Replace the flat 3-Wago junction box with four standing 221-423 bays.
    Pre-wired connectors drop in from above on 2 mm rails, with magnets and open wire slots in the front channel.
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2026-08-16 Tighten canal_test's magnet well to 8.2mm
    The default 8.4mm well (matched to canal's deep-well clearance)
    was too loose: the magnet fell out when the printed coupon was
    flipped. Try 8.2mm, closer to the boitier's 8.15mm friction fit,
    while still hoping to clear the well's 0.6mm face.
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2026-08-18 Relieve the screen wedge's bottom skirt for the LCD's flat cable.
    The real module arrived and the flex cable wrapping the panel edge stands
    proud of the PCB outline, which the pocket's 0.40mm clearance on the PCB
    does not cover. The skirt is thinned 0.6mm over the 18mm the cable spans,
    from z 13.60 to 18.60, taking the local clearance to 1.00mm.
    The top 1mm of frame stays full thickness so the glass still lands on an
    unbroken rim, and that lip prints as a 0.6mm overhang: slicing 0.0/0.4/0.6/1.0
    puts 0.6 at exactly one reclassified wall segment, no support and no change
    in time or weight, while 1.0 starts spreading overhang walls.
    No outside dimension moves and checks stay clean.
    Co-author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
2026-08-18 Stop chamfering the cable channel mouths inside the pocket.
    buried already leaves everything inside the pocket sharp, because the
    module covers it and a 1mm chamfer there only makes slivers. Its
    ceiling was seat_z (6.80), so the two channel mouths missed it by
    height alone: they rise to the PCB's back plane at 10.80, which is just
    as hidden.
    On the UART mouth the top corner chamfer ran from (53.55, 26.77) to
    (54.55, 25.77), 0.72mm past the top seat pad's edge in the pocket-wall
    plane. It took only skirt -- the facet is entirely at x >= 53.55 while
    the pad is 45.05 to 53.55, so the pad kept all 2.50mm around its bore
    -- but it read as a bitten-off pad corner.
    Aligning the mouth to the pad i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
2026-08-19 Fit the screen wedge's pocket to the real module, not the drawing.
    Two corrections from test-fitting the board in the printed wedge.
    The pocket was 0.5mm loose across the width, so module_clearance splits
    into module_clearance_width 0.25 and module_clearance_height 0.5 and the
    pocket goes 107.10 -> 106.60 wide. The screws do not move: they sit on
    the module's own 98.00 mount grid. pad_x follows the pocket wall to keep
    its 2.5mm of PETG around the bore, 8.50 -> 8.25.
    The 67.80 on the drawing is the PCB, not the glass. The board stands
    0.8mm past the glass and all of it is on the bottom edge, which is
    Waveshare's own room for the LCD flat cable. A 0.8 x 1.0mm lip now runs
    the width of the bo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
2026-08-19 Write down the three-node architecture, the BOM, and the filament per part.
    The README still described one Atom driving everything and two feedback
    sensors. There are three ESP32 nodes now: a Sensor Atom inside the machine
    reading flow, temperature and pressure, a Control Atom on top driving the
    230 V side, and the Waveshare screen, chained over UART. Each node gets a
    BOM table naming the connector and the wires on it, so the wiring is a
    lookup rather than a memory.
    The mechanical section listed boxes that no longer match what gets printed.
    It now lists the six objects, each with where it sits and what it is made of.
    Filament: PETG everywhere except screen_wedge. PLA creeps under sustained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
2026-08-21 Raise the screen seat to 30mm, and compute the ridge from a backing parameter.
    seat_height 20 -> 30 for more room under the screen. The ridge had to follow
    it one for one to keep all 77.8mm of the wedge on the slope, so north_height
    is gone as a parameter and the ridge is now seat_height + backing*sin(tilt).
    Backing is the number with meaning, and both seat_height and tilt used to
    drift it silently: the assembly's tilt slider swung it from 95.3mm at 45deg
    to 69.8mm at 75deg with nothing saying so.
    Geometry is unchanged to 0.02mm, the old hand-rounded 97.4 against the exact
    97.38. Checks clean, 2h28m and 101g.
2026-08-22 Threaded cable gland for the corner channel
    canal_angle, its lid, passe_cable, ecrou_passe_cable and the assembly.
    All five now pass nurb check clean.
    The thread was broken at the kernel level: `collar.fuse(core).fuse(crest)`
    silently returned the crest alone, 94mm3 instead of 1179, so the gland's
    barrel was a hollow ribbon in mid-air. Core + crest first, then the collar.
    The two Ø5.2 cable bores were vanishing the same way: chamfering the flange
    rim on a body that already carried them made OCCT heal them shut (2124mm3
    polished against 1709 draft), so the bores are cut after the polish now.
    Pitch goes 1.41 -> 2.0. At 1.41 the 35° flank and the 45° return eat 1.36
    of the pitch and leave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
2026-08-25 Add 230V wiring/EMI notes, sensor unit tests, and a filter variant note
    Documents the two manual-button wiring options (ESP32-mediated vs
    hardware-autonomous) and cable choices for the 230V and 5V signal runs.
    Adds Python unit tests for the flowmeter, temperature, and weight
    sensors, and flags a lower RC cutoff as an untried alternative for the
    Digmesa signal filter.
2026-08-25 Weigh the drip tray on a 5 kg load cell, without drilling the machine.
    Two PETG parts in the Profitec Go's drip pan: base_pesage carries the fixed
    end of the bar and cages the tray, plateau_pesage sits on the loaded end and
    holds the tray. The pan is never drilled — the base locates on the two
    existing screw heads and is held down by two magnets.
    The vertical stack closes to 0.0 mm against an 18.0 mm budget, so the load
    path is what drives every dimension: countersunk M4 at the anchored end
    because a proud head would lift the base off the sheet, two headless studs at
    the loaded end because 2.3 mm fits no head at all, and an adjustable M2.5
    overload stop because the pan's own rails only ca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
2026-08-25 Poser le socle sur les vis de la paroi arrière, et fermer les puits de goujon
    Les deux vis basses du châssis sortent de la paroi arrière, pas du fond :
    correction utilisateur sur photo. Entraxe 98 → 100, axe de tête à z = 5,0,
    saillie de 4 mm désormais horizontale. Les deux lamages verticaux deviennent
    des tunnels carrés percés dans la face nord, fermés dessus et dessous pour
    que l'eau du bac n'entre pas sous le bossage. Interférence tête/socle
    mesurée à 0,00 mm³.
    Deux aimants → cinq : deux de plus dans les angles arrière, avec la dalle
    locale que la bande arrière de 6,3 mm et les rails de 8,5 mm ne permettaient
    pas d'éviter, et un cinquième couché contre la paroi nor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
2026-08-31 Add wago_snap: magnetic Wago 221 clip rebuilt from the DIN holder.
    Press-fit profile taken from wago3.stl, DIN hooks dropped, magnet wells printed on-edge with a 45° roof so the snap stays in the layer plane.
    [wago3.stl]
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2026-09-02 Add ESP32-S3-Touch-LCD-4.3 hardware bring-up test
    Arduino sketch validating flash, the 800x480 RGB/ST7262 panel and the
    GT911 touch controller on the Waveshare screen: draws "Hello world" and
    a REBOOT button, with a live touch-coordinate debug line.
    Talks to the GT911 directly over I2C rather than through bb_captouch:
    that library probes the TMA445 touch chip's address 0x24 before GT911's,
    and 0x24 is also the CH422G IO expander's mode-register address on this
    board, which ACKs and causes a false-positive mis-detection.
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2026-09-03 Replace AC south hooks with towers and cut matching dimmer/SSR slots in AC and DC.
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2026-09-04 feat(print): butée d'arrêt AC séparée de la traverse, réglages ajustés
    Corrige l'élargissement de 10mm de la traverse (erreur du commit précédent) :
    la traverse reprend sa taille d'origine et la butée d'arrêt est posée 11mm
    à l'est, distincte d'elle. butee_depuis_ouest monté à 8mm, rebord réduit à
    4mm. Côté DC, décale le puits/muret NE de 2mm/2,5mm et retire le chanfrein
    sud du muret ouest. Documente l'orientation nord/sud/est/ouest dans CLAUDE.md.
2026-09-04 fix(print): flush wedge fit on screen_base, sync screen_assembly
    screen_base: fixed two polish bugs where a narrow per-edge check missed
    part of a mating face's perimeter, leaving a visible chamfer where the
    wedge presses or rests flush (side panel inner face, shelf inner face).
    Replaced with on_flat_face(), which excludes the whole face by its X
    plane instead of naming individual edges.
    Also removed the notch relief cut entirely: it sat exactly tangent with
    the rail's inner face at channel_half, and once the panel/shelf chamfer
    bugs above were fixed it stopped being masked, showing as a visible
    glitch at the seam. Widening the cut by a small overlap only moved the
    same tangent slivers else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
2026-09-04 fix(print): réduit les trous de passe_cable à Ø3.5 pour câbles 0.25mm²
    Les deux conducteurs torsadés + gaine thermo font 3.1mm de diamètre,
    plus fin que les câbles 0.75mm² d'origine (4.8mm) — cable_od_passe et
    passe_cable_passage mis à jour en conséquence.
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2026-09-07 boitier_dc: shift CAN support east, thicken NW Wago wall, derive CAN placement from spec
    Two independent tweaks first: CAN insert/leg assembly shifted +1mm east,
    and the NW Wago compartment's east wall (muret) thickened +3mm east.
    Then the CAN module's mounting holes were re-derived from its own
    published dimensions instead of hand-tuned offsets (scans/canpal.stl +
    slicer reading of the official model): 20.32mm wide, 15.24mm hole pitch,
    2.54mm hole-to-edge. insert1_cx/insert2_cx renamed insert_can_east_cx/
    insert_can_west_cx. muret_x1 (the NW Wago wall's east face) is now set
    backward from the east wall, leaving exactly the module's width plus a
    new jeu_can_x clearance parameter, rather tha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
    [canpal.stl]
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2026-09-08 firmware phase 2 : Unit CAN sur le XIAO, TX/RX corrigé, bring-up réel validé
    - CAN Pal AliExpress abandonné (sous-tension 3,3V) au profit d'un M5Stack
    Unit CAN (CA-IS3050G), même module que can-monitor.
    - Brochage GPIO7/GPIO8 inversé par rapport à l'ancien CAN Pal : les noms
    CAN_TX/CAN_RX du module sont ceux du transceiver, pas une convention
    câble croisé. Validé par self-test TWAI en boucle isolée puis sur bus réel.
    - can-monitor émet désormais un PING périodique (src=kScreen) pour obtenir
    un vrai PONG sans attendre l'écran de la phase 3.
    - Round-trip PING/PONG confirmé sur le bus, compteurs d'erreur TWAI à zéro
    en régime établi.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
    [main.cpp]
2026-09-08 firmware phase 2 terminée : can-monitor devient un pont série↔CAN pour coffeetool
    can-monitor n'est plus un simple moniteur texte : il pilote le driver
    usb_serial_jtag en direct (console coupée) pour faire un pont binaire
    COBS+PDU+CRC16 identique à celui prévu pour l'écran en phase 3. coffeetool
    peut donc envoyer PING/SET/STOP/RESET/REQSTATUS vers sensors sans attendre
    l'écran.
    Reste de la phase 2 bouclé sur le vrai matériel via ce pont : LOG au boot,
    RESET, bail, verrou 60s (piège du reset logiciel confirmé, et levée à la
    vraie coupure secteur confirmée), présence (coupure du bus CAN → repli
    sécurité confirmé).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
    [main.cpp]
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2026-09-08 firmware phase 4 (capteurs) : réception FLASH_CTRL/FLASH_DATA, validée sur matériel
    Réception OTA côté sensors (écriture au fil de l'eau, CRC16 par bloc, CRC32
    global, PENDING_VERIFY + timer d'invalidation). Trois essais de la checklist
    phase 4 vérifiés contre can-monitor : image saine, image cassée (rollback
    automatique), coupure CAN en plein transfert (otadata intact, pas de reboot).
    Deux bugs corrigés côté client coffeetool (pas dans le firmware) : attente
    d'acquittement qui n'ignorait pas les trames LOG intercalées, et envoi des
    FLASH_DATA sans pacing qui saturait le pont can-monitor.
    [main.cpp]
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2026-09-08 firmware phase 3 : barrière A atteinte, pont écran↔CAN fonctionnel dans les deux sens
    Deux bugs de bring-up UART trouvés et corrigés dans firmware/screen (régression
    IDF v5->v6.1 sur uart_set_pin()/RX, et uart_read_bytes(portMAX_DELAY) qui ne se
    réveille jamais sur UART_NUM_2 réaffecté) : PING/PONG confirmés dans les deux
    sens à travers le vrai pont écran, injection de commandes depuis le Mac comprise.
    [main.cpp]
2026-09-09 firmware phase 3 : barrière A close (test d'endurance TWAI, 3 min)
    Compteurs d'erreur TWAI restés à zéro sur 3 minutes à travers le pont
    écran↔CAN — critère de sortie de la barrière A. Doc mise à jour avec le
    résultat, une note sur le flapping PRESENCE_LOST normal à ce stade (pas de
    trafic keepalive périodique avant phase 5/6), et une checklist de mise en
    route pour éviter les pièges rencontrés (buffering coffeetool, ports
    concurrents, distinction sensors/screen par flash-id, power-cycle physique
    vs reset logiciel).
    can-selftest : correction du brochage par défaut (Unit CAN, pas l'ancien
    CAN Pal) et mise à jour de canpal-findings.md avec la vraie cause du CAN Pal
    (SLNT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
    [main.cpp]
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2026-09-09 firmware phase 5 : XDB401 (pression/température) validé sur capteur réel
    Driver I2C dans firmware/sensors (esp_driver_i2c, GPIO5/GPIO6, port R1) :
    déclenchement de conversion, scrutation du bit Sco pour la fin de
    conversion (repli sur délai fixe), lecture pression/température en deux
    transactions séparées (pas une rafale unique — l'exemple constructeur fait
    pareil, une rafale donnait une pression instable). REQSTATUS gère
    kStatusPressure avec période/plancher, tâche dédiée pressure_task pour ne
    pas bloquer la boucle de sécurité pendant la conversion (~50 ms).
    Validé en soufflant dans le capteur : deux pics nets et cohérents dans une
    capture de 10 s, confirmant toute la ch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
    [main.cpp]
2026-09-09 firmware phase 5 : débitmètre en cours (0 impulsion, non résolu) + bit flags généralisé
    Débitmètre (GPIO44/D7, Digmesa) : ISR front descendant, compteur 32 bits,
    STATUS_FLOW câblés. Bug GPIO44=RX UART0 par défaut trouvé et corrigé (même
    piège que le bug 1 de la phase 3, esp_private/gpio.h), mais aucune impulsion
    comptée malgré plusieurs souffles - debug ESP_LOGI laissé en place pour la
    reprise, tensions mesurées au repos (VCC 5,14V, SIGNAL 2,64V) notées dans
    firmware-implementation.md comme piste à trancher.
    Généralisation du bit "capteur valide" (StatusPressurePayload.flags bit0,
    ex-"I2C ok") à tous les STATUS_* : détection réelle en I2C (XDB401),
    toujours fixé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
    [main.cpp, messages.hpp]
2026-09-09 firmware phase 5 : débitmètre validé (câblage SIGNAL/VCC inversé, pas un bug firmware)
    Le débitmètre publie correctement STATUS_FLOW - validé en soufflant dans le
    capteur (0 impulsion au repos, comptage cohérent pendant le souffle,
    stabilisation à l'arrêt). Le bug logiciel réel (GPIO44 = RX UART0 par défaut,
    même piège que le bug 1 de la phase 3) est corrigé et reste en place.
    La cause de l'absence totale d'impulsion pendant la session de diagnostic
    était électrique, pas logicielle : le connecteur PANCOM du Digmesa n'a pas
    d'équivalent trouvé dans le commerce, un câble VH3.96 classique s'y enfiche
    à l'envers, inversant SIGNAL et VCC côté capteur. Corrigé au JST SM f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
    [main.cpp]
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2026-09-09 firmware phase 5 : dimmer validé bout en bout, barrière B atteinte
    Dimmer RBDimmer/DimmerLink : écriture DIM0_LEVEL confirmée fiable 0-100%,
    après correction d'un câblage phase/neutre inversé et une lecture des flags
    STATUS_ACTUATORS basée sur STATUS (bits READY/ERROR documentés) plutôt que
    sur ERROR seul, dont les valeurs observées ne correspondent pas à la doc
    fabricant. AC_FREQ/CALIBRATION restent peu fiables sur ce module même une
    fois prêt — traités en informatif seulement (docs/dimmerlink-i2c.md, doc
    complète des registres I2C trouvée en cours de session, remplace
    tests/test_rbi2c.py comme référence).
    firmware/dimmer-test/ : firmware jetable dédié pour le bring-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
    [main.cpp]
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2026-09-09 firmware phase 4 : OTA de screen validé sur le vrai matériel, barrière C fermée
    screen reçoit désormais FLASH_CTRL/FLASH_DATA pour son propre compte
    (même mécanique que sensors : PENDING_VERIFY, CRC16 par bloc, timer
    d'invalidation, validation post-boot via PING/PONG réel avec sensors),
    via un flash Mac->USB->screen direct qui ne passe jamais par le CAN.
    Trois essais faits (image saine, image cassée avec rollback, coupure
    en plein transfert), tous réussis.
    [main.cpp]
2026-09-09 firmware capteurs : rework SLNT validé, retour au CAN Pal
    Fil SLNT soudé au GND sur le CAN Pal (clone AliExpress) : le mode Silent
    qui bloquait l'émission est levé (17/17 PASS en auto-test isolé, tous
    compteurs d'erreur à zéro). Le module capteurs reprend le brochage CAN
    Pal (TX=GPIO7, RX=GPIO8) et abandonne le M5Stack Unit CAN qui servait de
    contournement pendant l'investigation. Validé de bout en bout avec
    l'écran branché sur le vrai bus (bail renouvelé en continu, aucune erreur
    TWAI).
    [main.cpp]
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2026-09-09 firmware phase 6, lot 2 : écran de service LVGL, bloqué sur glitch RGB résiduel
    esp_lcd RGB 800x480 + GT911 + esp_lvgl_port, bring-up CH422G via l'état RAM
    du lot 1, écran de service (version/CAN/événements/tactile). CAN continue de
    fonctionner dalle allumée (critère principal du lot). Reste bloqué sur le
    critère "texte stable" : glitch horizontal fort corrigé par les bons timings
    HSYNC/VSYNC (repris d'un sketch Arduino de référence), mais glitch résiduel
    ~10% persistant sur contenu qui change. avoid_tearing (double framebuffer
    matériel) essayé et abandonné : bug documenté dans le driver ESP-IDF v6.1
    lui-même (timing de bascule de framebuffer non garanti). Investigation
    c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
    [board.cpp, core.h, main.cpp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]
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2026-09-10 firmware phase 6, lot 4 : Wi-Fi, provisioning et NVS, validés sur le banc
    STA/AP, formulaire de provisioning, action « oublier le réseau », NVS de
    configuration et image factory archivée (v0.2.9). L'écran noir observé sur
    la première image v0.2.22 venait de Wi-Fi/HTTP initialisé avant les buffers
    DMA du panneau RGB ; confirmé sur banc avec firmware/screen-lcd-test (bug de
    NVS non initialisé pour esp_wifi_init trouvé et corrigé au passage, puis
    même correctif d'affinité de cœur que le commit 4f74f52b porté vers ce
    projet de diagnostic). v0.2.23 livrée par OTA et validée par PING/PONG CAN.
    [partitions.csv]
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2026-09-12 Add HTTP sensor reset action
    [core.h]
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2026-09-15 fix(screen): add manual LCD resync
    [service_screen.cpp]
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2026-09-16 Fix screen touch offset and keypad modes
    [service_screen.cpp]
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2026-09-16 Fix LCD reset sequence at boot
    [board.cpp, service_screen.cpp]
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2026-09-17 attempt to fix top right corner of screen home page
    [service_screen.cpp]
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2026-09-23 Invert boiler SSR GPIO control
    [main.cpp]
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2026-09-25 Set boiler ready tolerance to one degree
    [config.h]
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2026-09-26 courbe NTC fixée sur courbe Gicar avec offset 14 degrés
    [core.h]
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2026-09-28 Shorten boiler PWM window and capture SSR state
    [core.h]
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2026-10-01 pcb manual rework
    [screen_sensors_draft.kicad_pcb]
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2026-10-02 End filling on a relative pressure rise and pause during preinfusion
    The 02/10 brew dropped its first coffee 1.6 s after filling ended and
    put 8 g in the cup before reaching 8 bar. Filling waited for 0.4 bar
    absolute while the floor sat at 0.26 bar, and preinfusion at 60 %
    kept admitting water at full rate.
    Config schema 8 (migrated from 7):
    - filling.pressure_rise_bar replaces the absolute target: filling ends
    when pressure stays 150 ms above the lowest valid reading since the
    1 s guard plus the rise (0.05-0.50 bar, default 0.10). Replayed on
    the ten captures since 27/09: 7.5-16.2 ml instead of 10.7-17.7 ml.
    - The preinfusion pressure exit and preinfusion.pressure_bar are
    removed;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
    [config.h]
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2026-10-04 Show the brew on a single screen with a phase strip and a shot summary
    From "infuser" to "fermer", a brew now has its own screen: a strip of
    the phases (preheat, filling, preinfusion, ramp, infusion, drips) with
    their durations, six tiles (weight, infusion time, cup-weighted NTC
    mean / total time, infusion flow, thermal drop), then a live tile
    (heating, pump, scale and pump flow) next to "arrêter" while water
    flows, replaced by "fermer" once the pump stops. "fermer" stays dimmed
    with the capture countdown until the HF capture ends. Purge keeps the
    previous cycle screen.
    core/shot_summary.h builds the summary sample by sample during the HF
    capture, so a truncated capture keeps a complete su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
    [core.h]
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2026-10-04 Prune implemented plans from docs and drop doc references from code
    Delete plan-phase6.md, pid-infusion.md, heating-calibration.md,
    ble-test.md, support-digmesa.md and the throwaway firmware/ble-debug.
    Replace firmware-implementation.md with firmware-build.md (build, flash,
    bench, known pitfalls, open observations) and move the brew filling
    rationale into firmware.md. Clean ui.md: drop the lot plans, point the
    brew screen to ecran-infusion.md, and rebuild the settings table from
    core/config.cpp.
    Code comments no longer cite docs files; record_heating.py usage is
    documented in chauffe-chaudiere.md without the removed --mode flag.
    [board.cpp, core.h, main.cpp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]
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2026-10-06 Read the analog XDB401 on ADS1115 A2 and let the firmware time purges
    The screen reads A2 in the ADS1115 loop and exposes it as pressure.a2_raw
    in /telemetry and pressure_a2_raw in the HF capture. record_probe.py logs
    A2 and the I2C pressure, and purge.py hands the purge duration to
    purge.max_s so a lost purge_release no longer stretches a purge.
    docs/xdb401_swap.md tracks the sensor swap, its measurements and status.
    [boiler_ntc.cpp, core.h]
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2026-10-07 Run the screen from PSRAM and keep the panel out of standby
    Execute code and rodata from PSRAM so flash writes no longer disable the
    cache the RGB bounce-buffer ISR reads through: the image no longer slides
    while flashing. Drive DISP high from the first CH422G write and never
    lower it, so the panel no longer leaves standby mid-frame, as a trial
    against the random fixed boot offset. Show free internal SRAM and the
    largest block on the diagnostic and Wi-Fi screens. Bump to 0.3.45.
    [board.cpp, service_screen.cpp]
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2026-10-07 Replace sensors MINI controller with socketed XIAO ESP32-S3
    [sensors.kicad_pcb, sensors.kicad_sch, sensors_interfaces.kicad_sch]
2026-10-07 Read pressure from the analog XDB401 on A2 and retire the I2C probe
    The screen now converts A2 itself, (code - 3167.3) x 0.00075 bar: factory
    slope of 6 bar/V, zero read with the probe in open air. In a blind basket
    the OPV plateau minus the low state reads 9.80 bar, against 9.74 bar with
    the I2C probe, and 9.90 bar matches the needle gauge at 10 bar. This value
    feeds the UI, the filling and brew control, HF captures and /telemetry,
    and the screen no longer requests STATUS_PRESSURE over CAN.
    A2 is converted at 16 SPS: 62.5 ms spans about three pump strokes, and the
    standard deviation at the plateau drops from 66-169 to 11-27 codes.
    The sensors module loses its XDB401 I2C driver but keeps S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
    [boiler_ntc.cpp, main.cpp]
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
